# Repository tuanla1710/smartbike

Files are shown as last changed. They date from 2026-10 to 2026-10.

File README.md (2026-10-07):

# Smart Bike Controller V1

Firmware điều khiển xe đạp điện trên ESP32-S3-WROOM-1-N8 (flash 8 MB). Bản thiết kế nằm ở [docs/design/README.md](docs/design/README.md).

Build ảnh firmware chạy trên máy Linux và không cần mạch. Mạch chỉ cần khi nạp và mở console USB.

## Yêu cầu

| Thành phần | Ghi chú |
| --- | --- |
| Linux | Host đã dùng để cài ESP-IDF |
| Python 3 | Lệnh là `python3` |
| GCC | Dùng cho bộ đối chiếu luật điều khiển trên host |
| ESP-IDF v5.5.5 | Nằm ở `sources/esp-idf` |
| CMake và Ninja | ESP-IDF trên Linux không tự tải hai công cụ này |

## Cài ESP-IDF lần đầu

Từ thư mục gốc của repo:

```bash
git clone --depth 1 --branch v5.5.5 --recurse-submodules --shallow-submodules \
  https://github.com/espressif/esp-idf.git sources/esp-idf
cd sources/esp-idf
./install.sh esp32s3
python3 tools/idf_tools.py install cmake ninja
cd ../..
```

`install.sh` tải toolchain Xtensa và Python vào `~/.espressif`. Lệnh `idf_tools.py` tải CMake và Ninja vào cùng chỗ khi máy chưa có hai gói đó.

Mỗi terminal mới phải nạp môi trường trước khi gọi `idf.py`:

```bash
. sources/esp-idf/export.sh
```

Dấu chấm đầu dòng là bắt buộc. Sau khi nạp, `idf.py --version` in `ESP-IDF v5.5.5`.

## Kiểm tra luật điều khiển trên host

Bước này biên dịch lõi C bằng GCC của máy và so với giả lập Python. Chạy trước khi nạp mạch:

```bash
make -C firmware/host
cd firmware
python3 host/diff_oracle.py
python3 -m unittest sim.test_sim
```

Kết quả đúng là `ok files=8 cases=14` và unittest OK. REPL giả lập:

```bash
cd firmware
python3 -m sim
```

## Build firmware

```bash
. sources/esp-idf/export.sh
cd firmware
idf.py set-target esp32s3
idf.py build
```

`set-target` chỉ cần lần đầu, khi chưa có `firmware/sdkconfig`. Các lần sau chỉ cần `idf.py build`.

Ảnh nạp: `firmware/build/smartbike.bin`. Phân vùng ứng dụng là 2 MB (`firmware/partitions_8mb.csv`).

## Nạp và mở console

Cắm cáp USB vào cổng USB của module. Cổng thường là `/dev/ttyACM0`. Kiểm tra bằng `ls /dev/ttyACM*`.

Trong thư mục `firmware/`, shell đã nạp `export.sh`:

```bash
idf.py -p /dev/ttyACM0 flash monitor
```

Dòng đầu console là `ok boot`. Thoát màn hình log bằng Ctrl+].

Nạp lại mà không mở log:

```bash
idf.py -p /dev/ttyACM0 flash
```

Console đi qua USB Serial/JTAG. Lệnh debug nằm ở [docs/design/09-debug-commands.md](docs/design/09-debug-commands.md).

Chạy kịch bản portable trên mạch đã nạp (cần `pyserial`):

```bash
python3 -m pip install -r tools/requirements.txt
python3 -m sim.runner --port /dev/ttyACM0 scenarios/portable/boot.txt
```

Lệnh `hw` và `tick` chỉ có trên giả lập. Trên mạch, `hw` trả `err sim-only`.

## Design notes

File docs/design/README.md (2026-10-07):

# Smart Bike Controller — PCB V1

Tài liệu này chốt bản thiết kế **PCB Smart Bike Controller V1** cho xe V5.

Sơ đồ nguyên lý KiCad đã có ERC sạch. Bản đặt linh kiện và hồ sơ chân nối cho khách nằm ở [đặc tả kết nối](../customer/SmartBike-V5-Ket-Noi.md). File thiết kế mở bằng `hardware/kicad/kicad.sh`.

Nếu một datasheet của linh kiện mua về khác bảng chân trong tài liệu này, datasheet thắng. Cập nhật lại tài liệu trước khi routing.

## Đọc theo thứ tự

| Tài liệu | Dùng khi |
| --- | --- |
| [01-architecture.md](01-architecture.md) | Nhìn toàn bộ hệ thống, phạm vi V1, các quyết định đã khóa |
| [02-schematic.md](02-schematic.md) | Vẽ từng sheet KiCad: net, chân, R/C, MOSFET, connector |
| [03-pcb-layout.md](03-pcb-layout.md) | Outline 70 × 50 mm, stackup 4 lớp, vùng đặt linh kiện, luật đồng |
| [04-firmware.md](04-firmware.md) | Map GPIO, địa chỉ I2C, state machine, hợp đồng với phần cứng |
| [05-bom-and-bringup.md](05-bom-and-bringup.md) | Designator, footprint, mục BOM, thứ tự cấp nguồn lần đầu |
| [Đặc tả kết nối](../customer/SmartBike-V5-Ket-Noi.md) | Bảng chân J1–J8, MOD1, I2C, UART, điểm đo — bản giao cho người tích hợp dây |
| [06-software.md](06-software.md) | Ngôn ngữ, cây source ESP-IDF, task, BLE, thứ tự viết |
| [07-software-architecture.md](07-software-architecture.md) | Tầng, mặt phẳng, luật phụ thuộc, hợp đồng dữ liệu giữa khối |
| [08-control-algorithms.md](08-control-algorithms.md) | Thuật toán điều khiển và flowchart Mermaid |
| [09-debug-commands.md](09-debug-commands.md) | Lệnh console USB để test và debug thủ công |
| [10-implementation-checklist.md](10-implementation-checklist.md) | Thứ tự viết firmware và điều kiện pass từng bước |
| [11-automation-test.md](11-automation-test.md) | Test tự động và bộ giả lập phần cứng |

## Thông số đã khóa

| Hạng mục | Giá trị |
| --- | --- |
| Tên | Smart Bike Controller V1 |
| Kích thước | 70.00 × 50.00 mm |
| Số lớp | 4 |
| Độ dày | 1.6 mm |
| Nguồn vào PCB | 5 V duy nhất |
| MCU | ESP32-S3-WROOM-1-N8 |
| Đèn, xi-nhan, còi | Low-side MOSFET, không relay |
| GPS | u-blox MAX-M10S + anten chip |
| LiDAR trước | Module VL53L1X, tầm khoảng 4 m |
| IMU | BMI270 |
| Ánh sáng | BH1750 |
| Đo V / I / P / năng lượng | INA228 + shunt 10 mΩ |
| Lập trình | USB-C, USB Serial/JTAG của ESP32-S3 |
| Radio | Wi-Fi và Bluetooth trên module |
| Firmware về sau | OTA trên flash 8 MB |

48 V không vào PCB. V1 không có 5G, CAN, camera, stage nguồn 48 V, hay MCU phụ.

## Việc còn mở trước khi đặt hàng PCB

1. Đo dòng còi V5, rồi chọn một trong hai footprint còi (`Q8A` hoặc `Q8B`).
2. Đo dòng từng đèn. `Si2302CDS` chỉ được gắn cho kênh dưới 1 A liên tục.
3. Chọn MPN anten GPS và chép mạng phối hợp từ datasheet anten vào `R17`, `C20`, `C21`.
4. Đối chiếu thứ tự chân module VL53L1X mua về với header `MOD1` trước khi khóa footprint.

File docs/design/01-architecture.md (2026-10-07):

# 1. Kiến trúc V1

## 1.1 Mục tiêu

PCB này là bộ điều khiển xe đạp điện V5. Nó lấy duy nhất 5 V từ nguồn ngoài, đo điện áp / dòng / công suất, nuôi ESP32-S3 ở 3.3 V, và đóng các tải 5 V bằng MOSFET kéo xuống mass.

Tải V1:

- đèn pha
- đèn hậu
- đèn phanh
- xi-nhan trái, xi-nhan phải, hazard
- còi
- một kênh AUX

Cảm biến V1:

- GPS để biết vị trí
- LiDAR phía trước, khoảng 4 m, để cảnh báo vật cản
- IMU để chống trộm, phát hiện chuyển động, ngã, va chạm, và đánh thức MCU
- cảm biến ánh sáng để bật đèn pha tự động

Người lái nói chuyện với xe qua công tắc tay lái và Bluetooth. USB-C dùng để nạp firmware và, khi chưa cắm nguồn xe, nuôi mạch ở mức dòng USB mặc định.

## 1.2 Phạm vi không làm trên PCB này

- Không đưa 48 V, pin xe, hay stage công suất động cơ vào PCB.
- Không dùng relay.
- Không thêm Arduino, STM32, hay MCU thứ hai.
- Không thêm 5G, CAN, camera, màn hình, hay sạc pin.
- Không tắt buck bằng GPIO. Ngủ của V1 là deep sleep của ESP32.

## 1.3 Sơ đồ khối nguồn

```
J1 +5V_IN
    │
    F1 3A
    │
    Q1  DMG2305UX          chống đảo cực
    │
    D2  SMAJ5.0A           TVS xuống GND
    │
    +5V_PROT
    │
    D3  SS54               chặn dòng chảy ngược ra J1
    │
    └──────────┬─────────── D4 SS34 ← F2 ← USB VBUS
               │
           +5V_MERGED
               │
           R2 10 mΩ        INA228 đo qua shunt
               │
           +5V_SYS
               │
     ┌─────────┼─────────┬──────────────┐
     │         │         │              │
   đèn       còi       AUX         U2 TPS62162-Q1
 (low-side) (low-side) (low-side)       │
                                         +3V3
                                         │
                              ESP32, cảm biến, GPS, USB I/O
```

Nhánh `5V LIGHTS`, `5V HORN`, `5V AUX` trong sơ đồ khối ban đầu là các MOSFET low-side từng kênh. Không thêm MOSFET high-side theo nhóm.

## 1.4 Sơ đồ khối tín hiệu

```
                         ESP32-S3-WROOM-1
                                │
           ┌────────────────────┼────────────────────┐
           │                    │                    │
         I2C                  UART                 GPIO
           │                    │                    │
     GPIO8 SDA            GPIO17 ← GPS TXD      đèn / còi / AUX
     GPIO9 SCL            GPIO18 → GPS RXD      công tắc tay lái
           │                                      IMU INT, LiDAR
     INA228  0x40
     BMI270  0x68
     BH1750  0x23
     VL53L1X 0x29
```

## 1.5 Quyết định đã khóa

| ID | Quyết định |
| --- | --- |
| QĐ1 | USB VBUS và nguồn J1 gặp nhau sau hai diode Schottky. `Q1` có source phía cầu chì và drain phía `+5V_PROT`. Khi USB kéo `+5V_PROT` lên, diode thân dẫn ngược về J1 và kênh cũng mở vì gate vẫn ở mass. `D3` nằm sau `Q1` để chặn đường đó. |
| QĐ2 | Shunt của INA228 nằm sau điểm cộng nguồn, trên đường vào `+5V_SYS`. Số đo là dòng thực sự nuôi đèn, còi, AUX và buck. |
| QĐ3 | `HAZARD_SW` không có GPIO riêng. Hai diode kéo `LEFT_SW` và `RIGHT_SW` xuống thấp khi bấm hazard. Firmware hiểu hazard khi cả hai chân cùng thấp. |
| QĐ4 | Sáu kênh đèn và AUX dùng `Si2302CDS`. Kênh còi có hai footprint loại trừ nhau. Chỉ hàn một cái sau khi đo dòng còi. |
| QĐ5 | Mỗi kênh tải có diode hồi tiếp. Còi là tải cảm, và dây đèn trên xe đủ dài để tạo xung áp. |
| QĐ6 | LiDAR là module VL53L1X hàn qua header, không phải die trần. |
| QĐ7 | Module MCU là `ESP32-S3-WROOM-1-N8`: flash 8 MB, không PSRAM octal. Đủ chỗ cho OTA hai phân vùng. GPIO35–37 không bị PSRAM chiếm, và V1 cũng không dùng chúng. |
| QĐ8 | Buck luôn bật khi có `+5V_SYS`. `EN` nối thẳng rail 5 V. |
| QĐ9 | I2C V1 chạy 100 kHz. |
| QĐ10 | `V_BCKP` của GPS nối 3.3 V. V1 không có pin backup; mất nguồn là mất hot start. |

## 1.6 Ngân sách dòng

Cầu chì `F1` là trần cứng: **3 A** trên đường nguồn xe.

| Nhánh | Trần dùng khi thiết kế |
| --- | --- |
| Toàn bộ `+5V_SYS` | 2.5 A liên tục, để cầu chì 3 A còn dư |
| Mỗi kênh `Si2302CDS` | 1 A liên tục |
| Còi | Chưa biết. Nếu một mình còi đã trên 3 A thì V1 không kéo được; phải đổi cầu chì, shunt, connector và MOSFET |
| USB | CC 5.1 kΩ khai báo thiết bị USB mặc định. Firmware và cảm biến chạy được trên USB. Đèn và còi không được bật khi chỉ có USB |
| `+3V3` | TPS62162-Q1 cấp tối đa 1 A. Đỉnh Wi-Fi của ESP32-S3 nằm trong trần này nếu GPS và LiDAR đang ở dòng bình thường |

Ước lượng 3.3 V khi đang chạy: ESP32 khoảng vài trăm mA lúc phát Wi-Fi, GPS khoảng 30 mA, module VL53L1X vài chục mA, BMI270 / BH1750 / INA228 dưới 2 mA cộng lại.

## 1.7 Ngủ và đánh thức

`U2` không bị cắt điện. Dòng tĩnh của buck khoảng 17 µA, cộng thêm cảm biến nếu firmware không đưa chúng vào standby.

| Mode | Phần cứng |
| --- | --- |
| SLEEP | ESP32 deep sleep. VL53L1X bị kéo `XSHUT` thấp. GPS để firmware đưa vào backup software nếu cần. BMI270 giữ một ngắt chuyển động |
| PARKING / ALARM / RIDING | ESP32 chạy. Chi tiết trạng thái nằm ở tài liệu firmware |

Nguồn đánh thức V1 là `GPIO38` (`IMU_INT`). Không có chân nguồn riêng để bật buck.

## 1.8 Bản đồ GPIO đã chốt

| GPIO | Net | Hướng | Chức năng |
| --- | --- | --- | --- |
| GPIO4 | `LIDAR_XSHUT` | ra | Reset / shutdown VL53L1X, active-low ở phía sensor |
| GPIO5 | `LIDAR_INT` | vào | Ngắt VL53L1X, open-drain, có pull-up |
| GPIO6 | `HORN_GATE` | ra | Cổng MOSFET còi |
| GPIO7 | `HEADLIGHT_GATE` | ra | Cổng MOSFET đèn pha |
| GPIO8 | `I2C_SDA` | hai chiều | I2C data |
| GPIO9 | `I2C_SCL` | ra | I2C clock |
| GPIO10 | `LEFT_GATE` | ra | Xi-nhan trái |
| GPIO11 | `RIGHT_GATE` | ra | Xi-nhan phải |
| GPIO12 | `TAIL_GATE` | ra | Đèn hậu |
| GPIO13 | `BRAKE_GATE` | ra | Đèn phanh |
| GPIO15 | `LEFT_SW` | vào | Công tắc trái, active-low |
| GPIO16 | `RIGHT_SW` | vào | Công tắc phải, active-low |
| GPIO17 | `GPS_TXD` | vào | UART RX của ESP32, nối TXD của MAX-M10S |
| GPIO18 | `GPS_RXD` | ra | UART TX của ESP32, nối RXD của MAX-M10S |
| GPIO19 | `USB_D_N` | USB | D− |
| GPIO20 | `USB_D_P` | USB | D+ |
| GPIO21 | `HORN_SW` | vào | Công tắc còi, active-low |
| GPIO38 | `IMU_INT` | vào | BMI270 INT1, đánh thức |
| GPIO39 | `LIGHT_SW` | vào | Công tắc đèn, active-low |
| GPIO40 | `BRAKE_SW` | vào | Công tắc phanh, active-low |
| GPIO41 | `AUX_GATE` | ra | Cổng MOSFET AUX |
| GPIO42 | `STATUS_LED` | ra | LED trạng thái trên PCB, active-high |

`GPIO0` chỉ phục vụ nút BOOT trên PCB, pull-up 10 kΩ. Không phải chức năng xe.

Các chân không dùng, để hở: `GPIO1`, `GPIO2`, `GPIO3`, `GPIO14`, `GPIO35`, `GPIO36`, `GPIO37`, `GPIO43`, `GPIO44`, `GPIO45`, `GPIO46`, `GPIO47`, `GPIO48`.

`GPIO0`, `GPIO3`, `GPIO45`, `GPIO46` là chân strapping. `GPIO45` và `GPIO46` có pull-down yếu bên trong và phải được thả nổi. `GPIO3` thả nổi. Không kéo `GPIO45` lên cao.

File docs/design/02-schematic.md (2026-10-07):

# 2. Schematic V1 — hợp đồng cho KiCad

Mỗi mục dưới đây là một sheet. Tên net viết hoa, dùng đúng chuỗi này trên mọi sheet. KiCad cần `PWR_FLAG` trên `+5V_IN` và `GND`.

Quy tắc chung:

- Tụ gốm, điện áp ghi là điện áp định mức, không phải điện áp làm việc.
- Điện trở 1% 0603 trừ khi ghi khác.
- Cổng MOSFET đèn có series 100 Ω và pull-down 100 kΩ xuống `GND`. Pull-down giữ tải tắt trong lúc ESP32 còn đang reset.
- Firmware phải ghi mức thấp ra mọi chân gate trước khi đổi chân đó sang output.

## 2.1 Sheet `power`

### Chuỗi nguồn xe

```
J1-1 +5V_IN
  │
 F1 3A
  │
 +5V_FUSED ──── Q1 source (DMG2305UX)
                 Q1 drain  ──── +5V_PROT
                 Q1 gate   ── R1 100k ── GND
                 D1 BZT52C5V6: cathode = source, anode = gate

D2 SMAJ5.0A: cathode = +5V_PROT, anode = GND

+5V_PROT ── D3 SS54 anode→cathode ── +5V_MERGED
```

`Q1` là P-MOSFET high-side. **Source ở `+5V_FUSED`, drain ở `+5V_PROT`.** Đảo hai chân này thì cắm đúng cực cũng không nuôi được mạch. Chân SOT-23 của DMG2305UX: 1 = Gate, 2 = Source, 3 = Drain. Đối chiếu lại footprint KiCad với datasheet Diodes trước khi xuất gerber.

Zener `D1` kẹp `VGS` khoảng −5.6 V. Điện áp làm việc chỉ khoảng −5 V; zener là lớp chặn khi có xung.

`D2` đặt sau MOSFET chống đảo cực. Chiều TVS một chiều: cathode lên rail, anode xuống mass. SMAJ5.0A có điện áp standoff 5.0 V, đánh thủng khoảng 6.4 V, kẹp khoảng 9.2 V ở dòng xung danh định. TPS62162-Q1 chịu được tới 17 V. Tải đèn trong xung đó có thể thấy quá 5 V cho tới khi `F1` đứt; đây là đặc điểm của TVS này, chấp nhận cho V1.

### Cộng nguồn với USB, không back-feed

```
+5V_PROT ── D3 SS54 ──┐
                      ├── +5V_MERGED
USB_VBUS ── F2 ── D4 SS34 ──┘
```

`D3` và `D4` là diode Schottky, anode phía nguồn, cathode phía `+5V_MERGED`.

Khi chỉ cắm USB, `+5V_SYS` thấp hơn VBUS khoảng điện áp rơi của `D4` (khoảng 0.3–0.4 V). Khi chỉ có nguồn xe, sụt nằm trên `D3`. Hai nguồn không được cấp ngược cho nhau.

`F2` là PTC 1.1 A hold trên đường USB. Đường USB không được phép nuôi còi hay cả cụm đèn.

### Đo công suất

```
+5V_MERGED ── R2 10 mΩ 2512 ── +5V_SYS

U1 INA228
  IN+  = +5V_MERGED     (phía nguồn của shunt)
  IN−  = +5V_SYS        (phía tải của shunt)
  VBUS = +5V_SYS
  VS   = +3V3
  GND  = GND
  A1   = GND
  A0   = GND
  SCL  = I2C_SCL
  SDA  = I2C_SDA
  ALERT = ALERT, R3 10k lên +3V3
```

Địa chỉ I2C: **0x40**.

Đi dây sense: hai đường `IN+` và `IN−` tách từ mép trong của hai pad shunt, không đi chung với đồng dòng mạnh. Đây là kết nối Kelvin.

`C1` 100 nF từ `VS` xuống `GND`, sát U1.

`C2` 22 µF 10 V X5R từ `+5V_SYS` xuống `GND`, đặt gần cụm MOSFET.

Ở 3 A, sụt shunt là 30 mV, tán nhiệt khoảng 90 mW. Điện trở shunt: **10 mΩ, 1%, 1 W, 2512**. Dải ADC V1 dùng thang ±163.84 mV (`ADCRANGE = 0`) để dòng xung của còi không bị cắt ngọn. Hằng số hiệu chuẩn nằm ở tài liệu firmware.

`ALERT` không vào GPIO ở V1. Firmware đọc INA228 theo chu kỳ. Chân `ALERT` vẫn có pull-up để không bị nổi.

### Buck 5 V → 3.3 V

`U2` = **TPS62162-Q1**, gói WSON-8 DSG 2 × 2 mm, đầu ra cố định 3.3 V, 1 A. Mã đặt hàng gợi ý: `TPS62162QDSGTQ1`.

| Chân | Tên | Nối |
| --- | --- | --- |
| 1 | PGND | GND, và exposed pad |
| 2 | VIN | `+5V_SYS` |
| 3 | EN | `+5V_SYS` |
| 4 | AGND | GND |
| 5 | FB | AGND (nối mass). Bản 3.3 V cố định; datasheet khuyên nối FB xuống AGND |
| 6 | VOS | `+3V3` |
| 7 | SW | `L1` phía buck |
| 8 | PG | `PGOOD`, kéo lên `+3V3` bằng `R4` 100 kΩ. Không vào MCU |
| EP | thermal | GND, vài via xuống lớp GND |

Phụ kiện, đúng bộ LC khuyến nghị của TI:

| Ref | Giá trị | Việc |
| --- | --- | --- |
| C3 | 10 µF, 25 V, X5R, 0805 | VIN xuống GND, sát chân 2 |
| C4 | 100 nF, 25 V, 0402 | VIN xuống GND, sát hơn C3 |
| L1 | 2.2 µH, Isat ≥ 1.6 A, có vỏ chắn | SW tới `+3V3`. Gợi ý: TDK VLF3012ST-2R2M1R4 hoặc tương đương shielded 3 × 2.8 mm |
| C5 | 22 µF, 10 V, X5R, 0805 | `+3V3` xuống GND, ngay sau cuộn |
| R4 | 100 kΩ | `PGOOD` lên `+3V3` |

Vòng dòng đầu vào: `C3` → VIN → PGND → GND của `C3` phải ngắn. Node `SW` giữ diện tích nhỏ, không kéo xuống dưới anten GPS.

## 2.2 Sheet `usb`

`J8` là USB-C 16 chân, receptacle bảng, ví dụ kiểu `TYPE-C-31-M-12`. Chỉ dùng USB 2.0. Các chân SuperSpeed để hở.

| Chân receptacle | Net |
| --- | --- |
| A4, A9, B4, B9 | `USB_VBUS` |
| A5 | `CC1` |
| B5 | `CC2` |
| A6, B6 | `USB_D_P` |
| A7, B7 | `USB_D_N` |
| A1, A12, B1, B12, shield | `GND` |
| A8, B8 (SBU) | để hở |
| TX/RX SuperSpeed | để hở |

| Ref | Giá trị | Việc |
| --- | --- | --- |
| R5 | 5.1 kΩ | `CC1` xuống `GND` |
| R6 | 5.1 kΩ | `CC2` xuống `GND` |
| U3 | USBLC6-2SC6 | ESD. `VBUS` pin của USBLC6 vào `USB_VBUS`, I/O vào D+ và D− phía connector, GND xuống mass |
| C6 | 100 nF | `USB_VBUS` xuống `GND`, sát J8 |
| R7 | 22 Ω | series trên `USB_D_P`, sát module ESP32 |
| R8 | 22 Ω | series trên `USB_D_N`, sát module ESP32 |
| C7 | DNP, 0402 | từ phía ESP32 của D+ xuống GND, vị trí để sẵn theo hướng dẫn Espressif |
| C8 | DNP, 0402 | tương tự cho D− |

`R7`/`R8` nằm gần module, không nằm gần connector. Cặp D+/D− là differential 90 Ω.

`F2` và `D4` chỉ đặt một lần, trên sheet `power`. Sheet `usb` giao ra net `USB_VBUS`.

ESP32-S3 không đàm phán USB-PD. Hai điện trở 5.1 kΩ chỉ xin dòng USB mặc định (tối đa khoảng 500 mA ở host tuân thủ). Đủ để nạp firmware và chạy MCU cùng cảm biến.

## 2.3 Sheet `mcu`

`U4` = **ESP32-S3-WROOM-1-N8**. Anten PCB in trên module. Không dùng bản WROOM-1U.

Chân nguồn và điều khiển:

| Chân module | Tên | Nối |
| --- | --- | --- |
| 1 | GND | `GND` |
| 2 | 3V3 | `+3V3` |
| 3 | EN | `EN` |
| 40 | GND | `GND` |
| 41 | EPAD | `GND` |

| Ref | Giá trị | Việc |
| --- | --- | --- |
| C9 | 10 µF, 10 V, 0603 | `+3V3` xuống GND, sát chân 2 |
| C10 | 100 nF, 10 V, 0402 | `+3V3` xuống GND, sát chân 2 |
| R9 | 10 kΩ | `EN` lên `+3V3`. Chân EN không được để nổi |
| C11 | 1 µF | `EN` xuống `GND`, tạo trễ bật |
| SW1 | nút nhấn 6 × 6 mm | `EN` xuống `GND`, reset |
| R10 | 10 kΩ | `GPIO0` lên `+3V3` |
| SW2 | nút nhấn 6 × 6 mm | `GPIO0` xuống `GND`, BOOT |

LED trạng thái, active-high:

```
GPIO42 ── R11 330 Ω ── D5 anode
D5 cathode ── GND
```

`D5` là LED xanh 0603. Dòng khoảng 4 mA.

`GPIO19` nối net `USB_D_N` sau `R8`. `GPIO20` nối net `USB_D_P` sau `R7`.

Các GPIO chức năng nối đúng bảng ở [01-architecture.md](01-architecture.md). Không nối gì vào GPIO45 và GPIO46.

UART GPS không dùng chân mặc định của UART1 trên module (`IO17` mặc định là `U1TXD`, `IO18` mặc định là `U1RXD`). Firmware phải gán qua GPIO matrix: RX = GPIO17, TX = GPIO18.

## 2.4 Sheet `sensors`

Một cặp pull-up cho cả bus. Nếu module VL53L1X đã có pull-up riêng, gỡ pull-up trên module hoặc không lắp `R13`/`R14`, chỉ để lại một cặp.

| Ref | Giá trị | Việc |
| --- | --- | --- |
| R13 | 4.7 kΩ | `I2C_SDA` lên `+3V3` |
| R14 | 4.7 kΩ | `I2C_SCL` lên `+3V3` |

### U1 INA228

Đã nối ở sheet power. Trên sheet này chỉ là các net `I2C_SDA`, `I2C_SCL`, `ALERT`.

### U5 BMI270

Gói LGA-14, 2.5 × 3.0 mm. I2C vì `CSB` nối `+3V3`.

| Chân | Tên | Nối |
| --- | --- | --- |
| 1 | SDO | `GND` → địa chỉ **0x68** |
| 2 | ASDX | để hở |
| 3 | ASCX | để hở |
| 4 | INT1 | `IMU_INT` = GPIO38 |
| 5 | VDDIO | `+3V3` |
| 6 | GNDIO | `GND` |
| 7 | GND | `GND` |
| 8 | VDD | `+3V3` |
| 9 | INT2 | để hở |
| 10 | OCSB | để hở |
| 11 | OSDO | để hở |
| 12 | CSB | `+3V3` |
| 13 | SCx | `I2C_SCL` |
| 14 | SDx | `I2C_SDA` |

| Ref | Giá trị | Việc |
| --- | --- | --- |
| C13 | 100 nF | VDD xuống GND, trong vòng 1 mm |
| C14 | 100 nF | VDDIO xuống GND, trong vòng 1 mm |

Đặt BMI270 xa vùng đồng chịu lực cơ khí lớn (góc lỗ vít, mép kẹp vỏ) để giảm lệch offset do strain.

Firmware phải nạp file init của Bosch trước khi đọc gia tốc và con quay.

### U6 BH1750FVI

Gói WSOF6. ADDR xuống mass → địa chỉ **0x23**.

| Chân | Tên | Nối |
| --- | --- | --- |
| 1 | VCC | `+3V3` |
| 2 | ADDR | `GND` |
| 3 | GND | `GND` |
| 4 | SDA | `I2C_SDA` |
| 5 | DVI | nút RC bên dưới |
| 6 | SCL | `I2C_SCL` |

`DVI` là chân reset bất đồng bộ và là điện áp tham chiếu I2C. Nó phải ở thấp sau khi VCC đã lên, rồi mới lên cao.

```
+3V3 ── R12 10k ── DVI ── C16 100 nF ── GND
C15 100 nF từ VCC xuống GND
```

Hằng số RC khoảng 1 ms, dài hơn thời gian VCC tăng, nên thỏa điều kiện tối thiểu 1 µs của datasheet ROHM.

Cửa sổ quang của BH1750 phải nhìn ra ngoài vỏ, không bị che bởi pin header hay thành nhôm.

### MOD1 VL53L1X

Module, không vẽ mạch sensor trần. Header 1 × 6, pitch 2.54 mm, net theo thứ tự sau. Silk phải in tên chân. Trước khi khóa footprint, đối chiếu đúng module sẽ mua: nhiều board GY-VL53L1X đảo SDA/SCL.

| Pin header | Net |
| --- | --- |
| 1 | `+3V3` |
| 2 | `GND` |
| 3 | `I2C_SDA` |
| 4 | `I2C_SCL` |
| 5 | `LIDAR_XSHUT` |
| 6 | `LIDAR_INT` |

| Ref | Giá trị | Việc |
| --- | --- | --- |
| R15 | 10 kΩ | `LIDAR_XSHUT` lên `+3V3` |
| R16 | 10 kΩ | `LIDAR_INT` lên `+3V3` |
| C17 | 100 nF | `+3V3` xuống GND tại header |

Địa chỉ mặc định **0x29**. `XSHUT` mức cao thì sensor chạy; GPIO4 kéo thấp để shutdown. Ngắt là open-drain.

Module đặt sát mép trước, cửa sổ laser nhìn về phía trước xe, không bị đồng hay vỏ che.

## 2.5 Sheet `gps`

`U7` = **u-blox MAX-M10S**. Đối chiếu pinout với datasheet UBX-20035208 của đúng lô mua. Các bản khác nhau gọi chân 15 là `Reserved` hoặc `VIO_SEL`. Cả hai trường hợp V1 đều **để hở chân 15**. Không nối chân 15 xuống mass: nếu đó là `VIO_SEL`, mass sẽ chọn IO 1.8 V trong khi bus UART của ESP32 là 3.3 V.

| Chân | Tên | Nối |
| --- | --- | --- |
| 1, 10, 12 | GND | `GND` |
| 2 | TXD | `GPS_TXD` → GPIO17 |
| 3 | RXD | `GPS_RXD` ← GPIO18 |
| 4 | TIMEPULSE | để hở |
| 5 | EXTINT | để hở |
| 6 | V_BCKP | `+3V3` |
| 7 | V_IO | `+3V3` |
| 8 | VCC | `+3V3` |
| 9 | RESET_N | để hở |
| 11 | RF_IN | net `GPS_RF` |
| 13 | LNA_EN | để hở. Không dùng chân này làm GPIO |
| 14 | VCC_RF | để hở khi dùng anten thụ động |
| 15 | Reserved / VIO_SEL | để hở |
| 16 | SDA | để hở. Không nối vào bus I2C của xe |
| 17 | SCL | để hở |
| 18 | SAFEBOOT_N | để hở |

| Ref | Giá trị | Việc |
| --- | --- | --- |
| C18 | 1 µF | VCC xuống GND |
| C19 | 100 nF | VCC xuống GND, sát chân 8 |

UART mặc định của module: 9600 8N1. Firmware được phép nâng baud sau khi đã bắt tay.

### Anten

`AE1` là anten chip GPS L1 1575.42 MHz, đặt ở mép trái PCB. Mạng pi:

```
U7 RF_IN ── R17 ── AE1 feed
             │
            C20 xuống GND (DNP cho tới khi có giá trị datasheet)
AE1 feed ── C21 xuống GND (DNP cho tới khi có giá trị datasheet)
```

`R17` khởi tạo là 0 Ω chỉ để mạch thông. Trước khi xuất gerber, thay `R17`, `C20`, `C21` bằng mạng phối hợp in trong datasheet của đúng MPN anten đã chọn. Đường `GPS_RF` là CPWG 50 Ω trên L1, lớp tham chiếu L2, không via.

MAX-M10S đã có SAW và LNA trong module. Anten thụ động không cần thêm LNA. `VCC_RF` và `LNA_EN` để hở.

## 2.6 Sheet `outputs`

Mọi kênh là low-side:

```
+5V_SYS ── tải ── net *_N ── drain MOSFET
                              source ── GND
GPIO ── 100 Ω ── gate
                 │
               100 kΩ
                 │
                GND

Diode hồi tiếp: cathode = +5V_SYS, anode = net *_N
```

| Kênh | MOSFET | Gate | Net drain | Series | Pull-down | Flyback | Connector |
| --- | --- | --- | --- | --- | --- | --- | --- |
| Đèn pha | Q2 Si2302CDS | `HEADLIGHT_GATE` GPIO7 | `HEADLIGHT_N` | R18 100 | R25 100k | D6 SS14 | J3-2 |
| Đèn hậu | Q3 Si2302CDS | `TAIL_GATE` GPIO12 | `TAIL_N` | R19 100 | R26 100k | D7 SS14 | J4-2 |
| Đèn phanh | Q4 Si2302CDS | `BRAKE_GATE` GPIO13 | `BRAKE_N` | R20 100 | R27 100k | D8 SS14 | J4-3 |
| Trái | Q5 Si2302CDS | `LEFT_GATE` GPIO10 | `LEFT_N` | R21 100 | R28 100k | D9 SS14 | J5-2 |
| Phải | Q6 Si2302CDS | `RIGHT_GATE` GPIO11 | `RIGHT_N` | R22 100 | R29 100k | D10 SS14 | J5-3 |
| AUX | Q7 Si2302CDS | `AUX_GATE` GPIO41 | `AUX_N` | R23 100 | R30 100k | D11 SS14 | J7-2 |
| Còi | Q8A hoặc Q8B | `HORN_GATE` GPIO6 | `HORN_N` | R24 100 | R31 100k | D12 SS34 | J6-2 |

Chân SOT-23 của Si2302CDS: đối chiếu datasheet Vishay khi gán footprint. Thông thường 1 = Gate, 2 = Source, 3 = Drain. Không lấy nhầm footprint P-channel.

`Q8A` là Si2302CDS, SOT-23. `Q8B` là MOSFET logic-level TO-252, MPN để trống. Gate, drain, source của `Q8A` và `Q8B` song song. **Chỉ hàn một trong hai.** Cả hai để DNP trên BOM cho tới khi có số đo dòng còi.

| Dòng còi đo được | Lắp |
| --- | --- |
| Dưới 1 A | Q8A Si2302CDS |
| 1 A đến 3 A | Q8B, MOSFET logic-level, RDS(on) thấp, VGS(th) đủ mở ở 3.3 V. Ứng viên để đánh giá: IRLR8726 hoặc tương đương TO-252. Chốt MPN trong BOM trước khi lắp |
| Trên 3 A | Dừng. Cầu chì, shunt, J1 và J6 của V1 không chịu được. Không vá bằng một MOSFET lớn hơn trên cùng PCB này |

`D12` là SS34 vì năng lượng xung của còi lớn hơn đèn. Sáu diode đèn là SS14.

High-side của mọi tải là cùng net `+5V_SYS`, lấy từ chân 1 của từng connector tải.

## 2.7 Sheet `handlebar`

`J2` JST-XH 8 chân.

| Pin | Net | Trong PCB |
| --- | --- | --- |
| 1 | `+3V3` | nguồn pull-up cho cụm công tắc |
| 2 | `GND` | mass công tắc |
| 3 | `LEFT_SW` | GPIO15 |
| 4 | `RIGHT_SW` | GPIO16 |
| 5 | `HORN_SW` | GPIO21 |
| 6 | `LIGHT_SW` | GPIO39 |
| 7 | `HAZARD_SW` | không vào GPIO |
| 8 | `BRAKE_SW` | GPIO40 |

Mỗi công tắc trên tay lái nối giữa chân tín hiệu và `GND`. Mức tác động là thấp.

Với từng net `LEFT_SW`, `RIGHT_SW`, `HORN_SW`, `LIGHT_SW`, `BRAKE_SW`, `HAZARD_SW`:

```
+3V3 ── 10 kΩ ── net ── 100 nF ── GND
                  │
                 J2
```

| Net | Pull-up | Tụ |
| --- | --- | --- |
| `LEFT_SW` | R32 10k | C22 100n |
| `RIGHT_SW` | R33 10k | C23 100n |
| `HORN_SW` | R34 10k | C24 100n |
| `LIGHT_SW` | R35 10k | C25 100n |
| `BRAKE_SW` | R36 10k | C26 100n |
| `HAZARD_SW` | R37 10k | C27 100n |

Tụ 100 nF lắp sẵn. Dây tay lái dài.

Hazard, không tốn GPIO:

```
LEFT_SW  ── D13 anode    D13 cathode ── HAZARD_SW
RIGHT_SW ── D14 anode    D14 cathode ── HAZARD_SW
```

`D13` và `D14` là BAT54. Khi `HAZARD_SW` bị công tắc kéo xuống mass, cả `LEFT_SW` và `RIGHT_SW` xuống khoảng 0.3 V. Khi chỉ bấm trái, diode ngược nên `RIGHT_SW` không bị kéo theo.

Firmware: hazard khi `LEFT_SW` và `RIGHT_SW` cùng thấp.

## 2.8 Connector tải

Tất cả là JST-XH, một loại crimp cho bản prototype. XH chịu khoảng 3 A. Nếu dòng còi đo được buộc phải đổi connector, J1 và J6 chuyển sang JST-VH ở bản sau; V1 vẫn vẽ XH.

| Ref | Pin | Net |
| --- | --- | --- |
| J1 | 1 | `+5V_IN` |
| J1 | 2 | `GND` |
| J3 | 1 | `+5V_SYS` |
| J3 | 2 | `HEADLIGHT_N` |
| J4 | 1 | `+5V_SYS` |
| J4 | 2 | `TAIL_N` |
| J4 | 3 | `BRAKE_N` |
| J5 | 1 | `+5V_SYS` |
| J5 | 2 | `LEFT_N` |
| J5 | 3 | `RIGHT_N` |
| J6 | 1 | `+5V_SYS` |
| J6 | 2 | `HORN_N` |
| J7 | 1 | `+5V_SYS` |
| J7 | 2 | `AUX_N` |

Silk mỗi connector ghi tên và số chân. Không dựa vào trí nhớ khi crimp.

## 2.9 Test point

Pad tròn 1.5 mm, xuyên lỗ hoặc SMD, có silk. Bắt buộc:

| TP | Net |
| --- | --- |
| TP1 | `+5V_IN` |
| TP2 | `+5V_SYS` |
| TP3 | `+3V3` |
| TP4 | `GND` |
| TP5 | `USB_D_P` |
| TP6 | `USB_D_N` |
| TP7 | `GPS_TXD` |
| TP8 | `GPS_RXD` |
| TP9 | `I2C_SDA` |
| TP10 | `I2C_SCL` |
| TP11 | `HEADLIGHT_GATE` |
| TP12 | `HORN_GATE` |
| TP13 | `LEFT_GATE` |
| TP14 | `RIGHT_GATE` |

Không đặt test point trên node `SW` của buck.

## 2.10 Thứ tự vẽ

1. `power` — gồm cả diode USB và shunt, vì các net nguồn sinh ra ở đây.
2. `usb` — J8, CC, ESD, series resistor.
3. `mcu` — module, EN, BOOT, LED.
4. `sensors` — I2C và ba thiết bị.
5. `gps` — UART và anten.
6. `outputs` — bảy kênh.
7. `handlebar` — J2 và hazard.

ERC phải sạch trước khi cập nhật PCB. Mọi chân để hở có chủ đích phải được đánh dấu no-connect, trừ các chân đã nói là để hở ở trên.

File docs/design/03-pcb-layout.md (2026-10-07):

# 3. PCB layout V1

Chỉ bắt đầu layout khi ERC của schematic đã sạch.

## 3.1 Tấm mạch

| Hạng mục | Giá trị |
| --- | --- |
| Outline | 70.00 × 50.00 mm |
| Gốc tọa độ | góc dưới-trái |
| Cạnh trước xe | y = 50 mm, mép trên |
| Cạnh sau, phía connector tải | y = 0 |
| Độ dày | 1.6 mm |
| Đồng | 1 oz cả bốn lớp |
| Via tín hiệu | khoan 0.3 mm, pad 0.6 mm |
| Via GND dưới exposed pad | khoan 0.25–0.30 mm, vài via trong pad U2 và U4 |
| Lỗ bắt vít | 4 × M2 (khoan 2.2 mm), tâm lỗ cách mép 3.5 mm, nếu lỗ trước không chạm vùng cấm anten thì giữ; nếu chạm thì bỏ hai lỗ trước |
| Fiducial | 3 fiducial 1.0 mm, cách mép ≥ 5 mm, không nằm trên vùng anten |

Silk mặt trên: `SMART BIKE V5  PCB V1` và `5V ONLY`.

## 3.2 Stackup

| Lớp | Vai trò |
| --- | --- |
| L1 | Linh kiện và tín hiệu |
| L2 | Mặt phẳng GND, liền nhất có thể |
| L3 | Power: polygon `+5V_SYS` và `+3V3` |
| L4 | Tín hiệu |

L2 không bị xẻ dưới đường USB, dưới module ESP32 (trừ vùng anten), hay dưới đường RF của GPS. L3 mang dòng tải; L1 bổ sung polygon ở kênh còi và ở đoạn shunt.

Không đổ `+5V_SYS` trên L2.

## 3.3 Vùng đặt

Nhìn từ phía trước xe, mặt top:

```
y = 50  FRONT
┌────────────────────────────────────────────┐
│ MOD1 VL53L1X          cửa sổ nhìn ra trước │
│                                            │
│ AE1 GPS          U5 BMI270        U4 ESP32 │
│ anten            U6 BH1750     anten module│
│ U7 MAX-M10S                      ở mép phải│
│                                            │
│ U2 buck          U1 INA228    Q2…Q8        │
│ F1 Q1 D2 D3              D6…D12            │
│ J1          J3  J4  J5  J6  J7             │
└────────────────────────────────────────────┘
y = 0   REAR
J2 có thể nằm cạnh trái nếu hàng XH phía sau không còn chỗ.
J8 USB-C nằm cạnh sau hoặc cạnh trái. Anten ESP32 chiếm mép phải, nên USB không đặt ở mép đó.
```

Hai vùng không trộn vào nhau:

- Phía trước và giữa: RF, ESP32, GPS, IMU, ánh sáng, LiDAR.
- Phía sau: cầu chì, buck, shunt, MOSFET, connector tải.

Khoảng cách tối thiểu giữa cuộn `L1` (node SW) và anten GPS: đặt buck ở góc sau, anten GPS ở mép trước-trái. Không đặt còi MOSFET cạnh module GPS.

## 3.4 ESP32

Module nằm mép phải, phần anten của module hướng ra ngoài cạnh phải.

Vùng cấm anten, theo hardware design guidelines của Espressif cho module có anten PCB:

- Không đồng trên **cả bốn lớp** dưới phần anten của module.
- Không linh kiện, không via, không đường mạch trong vùng đó.
- Anten module hướng ra mép mạch, phía ngoài không có đồng.
- USB và UART không đi sát anten.

`C9` và `C10` sát chân 2. Mass của hai tụ xuống L2 bằng via ngay cạnh pad GND.

## 3.5 GPS

- Anten chip ở mép trái, feed hướng vào trong.
- Cắt đồng theo đúng hình keep-out của datasheet anten đã chọn, trên các lớp mà datasheet yêu cầu. Thường là cắt L1 và không đổ đồng đối diện feed.
- Đường `GPS_RF` dài vừa đủ, CPWG 50 Ω, tham chiếu L2 liền, không via.
- `R17`, `C20`, `C21` sát chân `RF_IN`.
- Không cho node `SW`, cổng còi, hay đường `HORN_N` đi dưới module GPS.

## 3.6 Buck

Thứ tự vật lý sát nhau: `C3`/`C4` → `U2` → `L1` → `C5`.

- PGND và AGND gặp nhau tại exposed pad, rồi via xuống L2.
- Node `SW` chỉ là đoạn ngắn từ chân 7 tới `L1`.
- Không biến node `SW` thành test point.

## 3.7 Dòng mạnh

Shunt `R2` hướng sao cho đường dòng đi thẳng từ `+5V_MERGED` sang `+5V_SYS`. Hai đường sense rẽ từ mép pad, cặp với nhau, tới `IN+` và `IN−`.

| Đường | Đồng tối thiểu |
| --- | --- |
| `+5V_IN` tới `F1`, qua `Q1`, tới shunt | polygon, tương đương ≥ 3 mm trên 1 oz, hoặc rộng hơn trên L1 + L3 |
| `+5V_SYS` trục chính tới J3–J7 | polygon L3, và nhánh L1 ngắn tới từng connector |
| `HORN_N` từ J6 tới drain Q8 | polygon ≥ 4 mm, hoặc L1 + L3 nối via dày |
| Các net đèn `*_N` | ≥ 1.0 mm nếu dòng kênh dưới 1 A; tăng theo số đo thực |

MOSFET ngồi cạnh connector của chính nó. Không kéo `HORN_N` vòng lên vùng GPS.

`F1` gần J1. `D2` gần `Q1`, dây mass của TVS ngắn xuống via L2.

## 3.8 Tín hiệu

- I2C đi ngắn giữa ESP32, U1, U5, U6 và MOD1. Kéo xa khỏi node `SW` và khỏi polygon còi.
- Cặp USB 90 Ω ± 10%, cùng dài, cùng lớp, tham chiếu L2. Ít via. Nếu phải via, thêm via mass cạnh đó.
- `GPS_TXD` và `GPS_RXD` là đường chậm, vẫn không luồn dưới anten.
- Cổng MOSFET là tín hiệu số thường. Series 100 Ω đặt gần GPIO của ESP32.

## 3.9 LiDAR và ánh sáng

`MOD1` sát y = 50, thân module có thể nhô khỏi outline nếu datasheet module cần khoảng trống phía trước cửa sổ. Ghi vùng cấm cơ khí trên lớp User: không vít, không gân vỏ, không dây trong hình nón nhìn của VL53L1X.

BH1750 quay cửa sổ lên trên hoặc ra mép, nơi vỏ có lỗ ánh sáng. Không đặt ngay dưới header.

## 3.10 Trước khi xuất gerber

- ERC sạch, DRC sạch.
- Không đồng trong keep-out anten ESP32 và keep-out anten GPS.
- L2 còn liền dưới USB và dưới ESP32 phần không phải anten.
- Đã điền MPN anten và giá trị `R17`/`C20`/`C21`.
- Đã quyết định `Q8A` hoặc `Q8B`, footprint còn lại để DNP và không bị DRC hiểu nhầm là chưa nối. Hai MOSFET song song là cố ý.
- Silk đọc được tên J1–J8 và chiều chân 1.
- Không có net 48 V nào trong schematic.

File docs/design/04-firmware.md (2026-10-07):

# 4. Firmware V1 — hợp đồng với PCB

Firmware nằm ở `firmware/`. Phần này khóa những gì firmware phải giả định đúng với PCB V1. Ngôn ngữ, cây ESP-IDF, task và hợp đồng BLE nằm ở [06-software.md](06-software.md).

## 4.1 Cây module

Các khối dưới đây là ranh giới module, không phải cây file. Cây file thật nằm ở [06-software.md](06-software.md).

```
smartbike/
├── main/
├── power/
│   ├── power_monitor      INA228
│   └── power_modes        sleep / parking / riding
├── sensors/
│   ├── gps                MAX-M10S, UART
│   ├── lidar              VL53L1X
│   ├── imu                BMI270
│   └── light              BH1750
├── vehicle/
│   ├── lighting           pha, hậu, PWM
│   ├── turn_signal        trái, phải, hazard
│   ├── brake
│   └── horn
├── security/
│   ├── anti_theft
│   └── motion_detect
├── bluetooth/
├── usb/
└── config/
```

## 4.2 Chân và mức tích cực

Tất cả công tắc tay lái là **active-low**, có pull-up trên PCB. Firmware bật pull-up nội bộ là tùy chọn, không bắt buộc.

Tất cả gate MOSFET là **active-high**. Mức thấp nghĩa là tải tắt. Trong `app_main`, trước khi cấu hình thành output, ghi 0 cho GPIO6, GPIO7, GPIO10, GPIO11, GPIO12, GPIO13, GPIO41.

`STATUS_LED` (GPIO42) active-high.

`LIDAR_XSHUT` (GPIO4): mức cao cho sensor chạy, mức thấp để shutdown. Pull-up 10 kΩ trên PCB nên nếu GPIO thả nổi thì sensor bật. Lúc vào sleep, firmware phải chủ động kéo thấp.

`IMU_INT` (GPIO38) là nguồn đánh thức deep sleep.

UART GPS, bắt buộc gán qua GPIO matrix:

| Tín hiệu ESP32 | GPIO | Nối tới |
| --- | --- | --- |
| UART RX | GPIO17 | MAX-M10S TXD |
| UART TX | GPIO18 | MAX-M10S RXD |

Không dùng mapping mặc định UART1 của module, vì mapping đó đảo chiều so với bảng này.

USB để nguyên GPIO19 = D−, GPIO20 = D+.

## 4.3 Bus

| Bus | Cấu hình V1 |
| --- | --- |
| I2C | GPIO8 SDA, GPIO9 SCL, 100 kHz |
| UART GPS | 9600 8N1 lúc mở cổng. Baud cao hơn chỉ sau khi module đã trả lời |

| Thiết bị | Địa chỉ 7-bit |
| --- | --- |
| INA228 | 0x40 |
| BH1750 | 0x23 |
| VL53L1X | 0x29 |
| BMI270 | 0x68 |

Quét I2C lúc bring-up phải thấy đủ bốn địa chỉ khi `XSHUT` đang cao. GPS không xuất hiện trên bus này.

BMI270 cần nạp init blob của Bosch trước khi đọc số liệu.

## 4.4 INA228

| Tham số | Giá trị V1 |
| --- | --- |
| Rshunt | 0.010 Ω |
| Dòng lớn nhất dùng để tính `CURRENT_LSB` | 5.0 A |
| `CURRENT_LSB` | 5 / 2^19 = 9.536743164 µA |
| `SHUNT_CAL` | 1250 |
| `ADCRANGE` | 0, thang vi sai ±163.84 mV |

Công thức TI: `SHUNT_CAL = 13107.2e6 × CURRENT_LSB × Rshunt`. Với hai số trên, kết quả đúng bằng 1250.

`ALERT` không nối GPIO. Đọc voltage, current, power, energy bằng I2C. Energy dùng cho màn hình điện thoại qua BLE.

Nếu shunt thực tế không phải 10 mΩ 1%, đo lại và sửa `SHUNT_CAL`. Không hard-code bù trong nhiều file; để một hằng trong `config`.

## 4.5 Đèn

| Việc | Hành vi V1 |
| --- | --- |
| Đèn hậu | Bật khi trạng thái là RIDING |
| Đèn phanh | Bật khi `BRAKE_SW` thấp |
| Đèn pha tự động | Lux dưới 100 thì bật. Lux trên 200 thì tắt. Trong khoảng 100–200 giữ nguyên trạng thái |
| `LIGHT_SW` thấp | Ép đèn pha bật, bỏ qua lux |
| `LIGHT_SW` cao | Trở lại chế độ lux |
| Độ sáng | PWM LEDC 1 kHz, 10 bit, trên các chân đèn. Còi và phanh không PWM ở V1 |
| Xi-nhan | Nhấp nháy 1.25 Hz, duty 50%, khi đúng một trong hai công tắc trái/phải đang thấp |
| Hazard | Khi cả `LEFT_SW` và `RIGHT_SW` cùng thấp. Không đọc chân hazard riêng. Hai bên nháy cùng pha |

Hazard bằng phần cứng diode nên firmware chỉ cần quy tắc `HAZARD = LEFT + RIGHT`.

## 4.6 Còi

`HORN_SW` thấp thì `HORN_GATE` cao. Thả công tắc thì gate thấp ngay.

V1 không PWM còi. Nếu dòng còi chưa được ghi vào `config`, firmware không bật còi cùng lúc với toàn bộ đèn. Trần phần cứng là cầu chì 3 A. Giới hạn thời gian giữ còi, cắt khi mất số đo dòng hoặc quá dòng, và cách tính “đang bật” của xi-nhan nằm ở [08-control-algorithms.md](08-control-algorithms.md). Mức tích cực của gate không đổi.

## 4.7 State machine

```
SLEEP
  │  IMU_INT
  ▼
PARKING
  │  người dùng bắt đầu chạy (BLE hoặc điều kiện start trong config)
  ▼
RIDING
  │  dừng
  ▼
PARKING
  │  chuyển động đáng ngờ
  ▼
ALARM
```

| Trạng thái | Việc nhìn thấy được |
| --- | --- |
| SLEEP | Gate đều thấp. `LIDAR_XSHUT` thấp. ESP32 deep sleep, wake trên GPIO38 |
| PARKING | Đèn pha theo lux hoặc theo `LIGHT_SW`. IMU theo dõi. GPS có thể giữ fix chậm |
| RIDING | Đèn hậu bật. Phanh, xi-nhan, còi theo công tắc. LiDAR cảnh báo. GPS cập nhật |
| ALARM | Nháy đèn, bật còi theo chu kỳ, gửi vị trí GPS và sự kiện qua BLE |

Ngưỡng “chuyển động đáng ngờ”, thời gian còi báo động, và cách xác nhận start/stop để trong `config`, không rải trong từng module. Điều kiện biên của từng chuyển trạng thái, khoảng nghỉ giữa hai lần báo động, và hủy ngủ khi có chuyển động mới nằm ở [08-control-algorithms.md](08-control-algorithms.md).

LiDAR khoảng 4 m là cảnh báo, không phải phanh tự động. V1 không có actuator phanh.

BLE V1 mang: trạng thái xe, lux, khoảng cách LiDAR, cờ IMU, tọa độ GPS, và số đọc INA228 (V, I, P, energy). OTA là việc sau, flash 8 MB đã chừa chỗ; bootloader OTA không bắt buộc phải xong trong bản firmware đầu tiên lên mạch.

## 4.8 Thứ tự bật

1. Mọi gate ghi 0, cấu hình output.
2. I2C 100 kHz, quét bus.
3. INA228: ghi `SHUNT_CAL`, kiểm tra điện áp bus khoảng 5 V (hoặc khoảng 4.6 V nếu đang nuôi bằng USB).
4. BMI270 init, bật ngắt chuyển động trên INT1.
5. BH1750, VL53L1X (`XSHUT` cao), UART GPS.
6. Vào PARKING. Chỉ vào RIDING sau điều kiện start.

Nếu chỉ có USB, bước 6 vẫn chạy nhưng các gate đèn và còi giữ thấp.

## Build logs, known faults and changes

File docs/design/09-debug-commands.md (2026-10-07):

# 9. Lệnh test và debug thủ công

Console này là đường điều khiển bằng tay trên USB Serial/JTAG, cùng cổng nạp firmware. Mỗi lệnh kiểm tra một nhánh đã khóa ở [08-control-algorithms.md](08-control-algorithms.md). Lệnh không mở thêm hành vi xe. Lệnh chỉ đưa đầu vào mà nhịp 10 ms vốn đã có, hoặc in trạng thái nhịp đó đang giữ.

## 9.1 Đường đi của một dòng

Task `console` đọc stdin, phân tích một dòng, rồi trả lời. Task này không gọi GPIO, LEDC, I2C, hay deep sleep. Mức tải chỉ đổi khi nhịp `vehicle` xử lý lệnh hoặc đọc khối debug.

```mermaid
flowchart TD
  line["Một dòng USB"] --> parse{"Đúng cú pháp?"}
  parse -->|không| err["err syntax"]
  parse -->|có| kind{"Loại lệnh?"}
  kind -->|xem| snap["Đọc bản sao snapshot"]
  snap --> pr["In một dòng ok"]
  kind -->|điều khiển| q{"Queue còn chỗ?"}
  q -->|không| full["err queue"]
  q -->|có| push["Đẩy command_t, in ok queued"]
  kind -->|debug| ses{"debug đang bật?"}
  ses -->|không| no["err debug"]
  ses -->|có| box["Ghi debug_ctrl, in ok"]
  push --> tick["Nhịp 10 ms lấy một lệnh"]
  box --> tick
  tick --> pipe["Chính sách rồi ống cổng ra"]
  pipe --> evt["evt ... khi trạng thái đổi"]
```

`arm`, `disarm`, `ride`, `dismiss`, `aux` đi vào cùng queue dài 4 với BLE. Một nhịp lấy một lệnh. Hàng đầy thì lệnh mới bị bỏ và console in `err queue` ngay, không chờ.

`hold` và `inject` ghi struct `debug_ctrl` trong RAM. Nhịp sau chép struct đó cùng lúc với perception. Tắt `debug` hoặc reset thì struct về rỗng. Reset không phải deep sleep cũng tắt arm, như mục 8.3.

## 9.2 Cú pháp và câu trả lời

Một dòng tối đa 80 byte, kết thúc bằng LF. Token cách nhau bởi một dấu cách, chữ thường, số thập phân. Không có dấu phẩy, không có chuỗi trong ngoặc.

Mỗi lệnh nhận đúng một dòng trả lời ngay:

| Dòng | Nghĩa |
| --- | --- |
| `ok` | Đã ghi nhận |
| `ok queued` | Đã vào queue, chưa phải đã đổi mode |
| `ok k=v k=v` | Kết quả đọc |
| `err syntax` | Thiếu token hoặc thừa token |
| `err range` | Số ngoài khoảng cho phép |
| `err debug` | Lệnh cần phiên debug mà phiên đang tắt |
| `err queue` | Queue đầy, lệnh không vào |
| `err nvs` | Ghi NVS thất bại |

Khi nhịp 10 ms thực sự đổi trạng thái, console in thêm một dòng `evt`, không thay dòng `ok`:

| evt | Khi |
| --- | --- |
| `evt arm=1` / `evt arm=0` | Arm đổi |
| `evt mode=parking` / `riding` / `alarm` | Mode đổi |
| `evt reject=<lệnh> <lý do>` | Lệnh bị mục 8.6 bỏ. Lý do là `mode` |
| `evt fault=1` / `evt fault=0` | `fault_latch` đổi |
| `evt inhibit=<mã>` | Lý do cấm tải đổi |
| `evt sleep=start` / `abort` / `enter` | Giao dịch ngủ |
| `evt hold=off` | Hết hạn giữ kênh |

Mã `inhibit`: `none`, `disarmed`, `power`, `uvlo`, `oc`, `fault`.

`firmware/tools/bringup_log.py` gửi đúng các dòng này và chỉ cần hiểu `ok`, `err`, `evt`.

## 9.3 Lệnh xem

Các lệnh này không cần `debug` và không vào queue.

| Lệnh | In ra | Dùng khi |
| --- | --- | --- |
| `help` | Danh sách lệnh, một lệnh một dòng `ok cmd=...` | Quên cú pháp |
| `status` | mode, armed, fault, uvlo, inhibit, debug, v, i, lux, range, motion | Nhìn một nhịp |
| `inputs` | raw và stable của sáu công tắc, kèm hazard | Soát debounce 30 ms |
| `sense` | bốn địa chỉ I2C còn sống, tuổi mẫu lux/range/power, gps_fix | Biết mẫu nào hết hạn |
| `power` | bus_mv, current_ma, power_dw, energy_mwh, power_valid | Đối chiếu INA228 |
| `gates` | duty và mức boolean muốn, rồi mức đã ghi ra chân | Thấy chốt arm và luật còi |
| `faults` | fault_latch, uvlo_count, cmd_dropped, failsafe_count, motion_fault, horn_lockout | Đếm lỗi |
| `config` | Mọi hằng RAM mục 8.2 | Xác nhận số đang dùng |
| `snapshot` | 32 byte BLE, hex liền | So với notify điện thoại |
| `watch <ms>` | Lặp `status` mỗi ms | Theo dõi liên tục |
| `watch off` | Dừng lặp | |

`watch` nhận 100 đến 5000. Task `console` tự in, nhịp 10 ms không gọi `printf`. `inputs` in cả `raw` và `stable` để thấy rung dưới 30 ms không đổi `stable`.

`gates` in hai lớp: `want_*` trước ống cổng ra và `out_*` sau ống. Bring-up chưa arm thì `want_head` có thể khác 0 trong khi `out_head` bằng 0.

## 9.4 Lệnh điều khiển

Cùng nghĩa với opcode BLE. Không cần phiên debug.

| Lệnh | Opcode | Việc của nhịp 10 ms |
| --- | --- | --- |
| `arm` | `0x03` | Bật arm, xóa `fault_latch`, ghi RTC |
| `disarm` | `0x04` | Tắt arm, xóa fault, xóa AUX, xóa khóa còi |
| `ride start` | `0x01` | `PARKING` sang `RIDING`. Mode khác thì `evt reject=ride_start mode` |
| `ride stop` | `0x02` | `RIDING` sang `PARKING`. Mode khác thì reject |
| `dismiss` | `0x05` | Trong `ALARM` thì về `PARKING`. Luôn xóa `fault_latch` |
| `aux on` | `0x06` | Chốt AUX |
| `aux off` | `0x07` | Nhả AUX |

`ok queued` chỉ nghĩa là hàng đã nhận. Mode mới nằm ở dòng `evt` của nhịp sau. Gõ `arm` rồi `ride start` trên hai dòng thì đúng luật một lệnh mỗi nhịp: arm trước, sang `RIDING` ở nhịp kế.

## 9.5 Phiên debug

`debug on` mở phiên trong RAM. `debug off` và mọi reset đều đóng phiên, xóa `hold` và `inject`. Phiên không ghi NVS, không sống qua deep sleep.

Lệnh mục 9.6 và 9.7 khi phiên tắt trả `err debug` và không ghi gì.

`debug` không in thêm. `status` có trường `debug=0|1`.

## 9.6 Giữ một kênh tải

Dùng khi đo dòng từng tải trên nguồn J1, đúng bước gắn từng tải một của bring-up.

| Lệnh | Tác dụng |
| --- | --- |
| `hold head on` | Ép duty pha = 1023 |
| `hold head <0..1023>` | Ép đúng duty |
| `hold head off` | Ép duty pha = 0 |
| `hold tail on\|off\|<duty>` | Đèn hậu |
| `hold left on` | `left_lit` true, duty vẫn theo pha 800 ms |
| `hold left off` | Duty trái = 0 và `left_lit` false |
| `hold left <0..1023>` | Ép đúng duty, không nhấp. `left_lit` true khi duty khác 0 |
| `hold right ...` | Cùng luật với trái |
| `hold brake on\|off` | GPIO phanh. Có duty thì `err syntax` |
| `hold horn on\|off` | GPIO còi người lái |
| `hold aux on\|off` | GPIO AUX |
| `hold off` | Xóa mọi ép kênh |

`hold horn on 500` thừa token, trả `err syntax`, không ép một nửa.

Kênh không bị `hold` vẫn do chính sách tính. Sau khi trộn, ống cổng ra chạy nguyên: chưa arm thì mọi chân vẫn thấp, mất số đo nguồn thì thấp, UVLO và quá dòng vẫn khóa, còi người lái vẫn chịu luật 30 s và luật chưa biết dòng còi. `hold` không tắt các luật đó.

Mỗi kênh đang giữ hết hạn sau 30 s rồi tự nhả, in `evt hold=off`. Muốn giữ lâu hơn thì gõ lại lệnh. Còi vì vậy không kêu mãi nếu cáp USB tuột giữa chừng.

`hold left on` và `hold right on` đi theo pha xi-nhan, nên nửa kỳ tắt vẫn có `left_lit` true. Số duty cố định chỉ dùng khi đo dòng, và lúc đó kênh không nhấp. Luật còi đọc cờ `lit`, không đọc duty tức thời.

## 9.7 Bơm đầu vào

Bơm thay giá trị mà chính sách và mode đọc. Không thay số đo nguồn. Áp và dòng trong ống cổng ra luôn là số của INA228.

| Lệnh | Khoảng | Thay cho |
| --- | --- | --- |
| `inject lux <0..65535>` | lux | BH1750 trong luật đèn pha |
| `inject lux off` | | Trả lux về cảm biến |
| `inject motion on` | | `motion` thô |
| `inject motion off` | | `motion` thô false |
| `inject clear motion` | | Trả chuyển động về IMU |
| `inject range <0..65534>` | mm | Khoảng cách LiDAR |
| `inject range off` | | Trả về cảm biến |
| `inject pin low` | | Chỉ vị từ “chân IMU thấp” trong luật xin ngủ |
| `inject pin high` | | Cấm xin ngủ theo luật phần mềm |
| `inject pin off` | | Trả về GPIO38 thật |
| `inject off` | | Xóa mọi bơm |

`inject range 65535` bị `err range` vì `0xFFFF` là mã không có mẫu. `inject range 0` hợp lệ và phải làm `obstacle` true. `inject range 4000` phải làm `obstacle` false.

`inject pin` không đụng `esp_sleep_enable_ext0_wakeup`. Chân thật vẫn là nguồn thức. Bơm `pin low` chỉ để đi hết giao dịch ngủ trên bàn khi chân đang cao. Nếu chân thật vẫn cao, chip sẽ thức lại ngay; `status` sau boot cho thấy reset deep sleep và arm còn hay không.

`sense` in cả giá trị cảm biến và giá trị sau bơm, với cờ `inj=lux` khi bơm còn hiệu lực. Người test không tưởng nhầm lux bơm là lux đo được.

## 9.8 Sửa hằng trong RAM

`config set <tên> <số>` sửa bản RAM. Nhịp sau dùng số mới. `config save <tên>` chỉ có với hai tên được ghi NVS, và ghi đó chạy trên task `console`.

| Tên | Khoảng | Cần debug | Được save |
| --- | --- | --- | --- |
| `horn_current_ma` | 0..5000, 0 là chưa biết | không | có |
| `shunt_cal` | 1..65535 | không | có |
| `stop_idle_s` | 5..3600 | có | không |
| `sleep_after_s` | 5..3600 | có | không |
| `alarm_s` | 1..120 | có | không |
| `alarm_gap_s` | 0..60 | có | không |
| `alarm_motion_ms` | 50..5000 | có | không |
| `debounce_ms` | 0..500 | có | không |
| `oc_ma` | 100..2500 | có | không |
| `uvlo_mv` | 3000..4500 | có | không |

`oc_ma` không đặt được trên 2500. `failsafe_ms` không có trong bảng. Reset đưa các tên không save về mặc định mục 8.2. `horn_current_ma` và `shunt_cal` đã save thì nạp lại từ NVS lúc boot.

`config set oc_ma 3000` trả `err range` và giữ số cũ.

## 9.9 Ngủ và quét bus

| Lệnh | Đường | Việc |
| --- | --- | --- |
| `sleep` | queue, cần debug | Nhịp sau xin ngủ nếu đang `PARKING`, đang yên, và vị từ chân IMU cho phép. Thiếu điều kiện thì `evt sleep=abort` kèm lý do `mode`, `motion` hoặc `pin` |
| `i2c` | cờ cho task `sensors` | Quét lại bus, in `ok addr=40,23,29,68` hoặc địa chỉ thiếu |

`i2c` không quét trên task console. Task `sensors` quét ở vòng của nó rồi console in kết quả. Quét trùng với giao dịch đang chạy thì vòng đó hoãn quét một nhịp, không chen giữa một lần đọc INA228.

## 9.10 Kịch bản gõ tay

Mỗi kịch bản giả định dòng `ok` đã về trước khi gõ dòng tiếp. Nguồn tải là J1 khi có lệnh `hold` hoặc `arm` mà công tắc đang bấm. Trên chỉ USB, arm vẫn bật được cờ nhưng ống cổng ra cấm tải nếu dòng tổng kéo sụt áp hoặc chạm ngưỡng quá dòng.

**Gate lúc boot.** `status` rồi `gates`. Kỳ vọng `armed=0`, `inhibit=disarmed`, mọi `out_*=0`.

**Debounce.** `watch 100`, bấm rồi thả từng công tắc. `raw` đổi ngay, `stable` đổi khi đủ `debounce_ms`. Rung nhanh hơn 30 ms thì `stable` đứng yên. `watch off`.

**Hazard.** Giữ trái và phải. `inputs` có `hazard=1`. Chỉ giữ trái thì `hazard=0` và `stable_right=0`.

**Arm không sống qua USB reset.** `arm`, thấy `evt arm=1`, nhấn reset. `status` có `armed=0`.

**Một tải.** Nguồn J1. `arm`, `debug on`, `hold head on`, đo dòng, `hold off`. Lặp `tail`, `left`, `right`, `brake`, `horn`, `aux`. Giữa hai kênh là `hold off`.

**Đèn pha.** `debug on`, `inject lux 99` thì `gates` có `want_head=1023` sau khi arm. `inject lux 100` giữ nguyên. `inject lux 201` thì `want_head=0`. `inject lux off` trả về cảm biến. Bấm `LIGHT_SW` trong lúc `inject lux 201` thì `want_head=1023`, thả thì về 0.

**Xi-nhan và luật còi.** `config set horn_current_ma 0` nếu đang khác 0. `arm`, `debug on`, `hold head on`, `hold tail on`, `hold left on`, `hold horn on`. Trái vẫn nhấp. `out_horn=0` cả ở nửa kỳ duty trái bằng 0. `hold left off` thì `out_horn` được phép lên 1. `config set horn_current_ma 800` rồi `config save horn_current_ma` khi đã đo dòng còi thật, luật cấm này hết hiệu lực.

**Còi 30 s.** `hold horn on`, chờ `evt hold=off`. Thả công tắc vật lý nếu đang kẹt, rồi `hold horn on` lại được.

**Quá dòng và khóa.** `debug on`, `config set oc_ma 100`, `arm`, `hold head on` với một tải nhỏ hơn cầu chì nhưng hơn 100 mA. Kỳ vọng `evt fault=1`, `out_*=0`. `hold head on` lần nữa không sáng cho đến `dismiss` hoặc `arm`. `config` sau reset hết `oc_ma` đã hạ.

**Mất số đo nguồn.** Rút tạm module hoặc để mẫu quá 200 ms trên bàn có kẹp. `inhibit=power`, mọi `out_*=0` dù `armed=1`.

**Mode.** `config set stop_idle_s 5` trong phiên debug. `ride start` chỉ từ `PARKING`. `inject motion on` rồi `ride start`: ở `RIDING` và không sang `ALARM`. `inject motion off`, sau 5 s có `evt mode=parking`. `ride start` lúc `mode=alarm` ra `evt reject=ride_start mode`.

**Báo động lặp.** `config set alarm_s 2`, `config set alarm_gap_s 5`, `config set alarm_motion_ms 400`. Về `PARKING`, `inject motion on`. Vào `ALARM` khoảng 400 ms, hết 2 s thì về `PARKING`, khoảng 5 s sau vào `ALARM` lại nếu bơm còn `on`.

**LiDAR không phanh.** `inject range 3999`. `status` có cờ vật cản, `out_brake` không đổi theo range. `inject range 4000` thì cờ tắt.

**Ngủ.** `config set sleep_after_s 5`, `inject motion off`, `inject pin low`, `sleep`. Có `evt sleep=enter` khi đủ yên. `inject motion on` trong lúc chờ thì `evt sleep=abort`.

**Hàng lệnh.** Không có lệnh riêng để làm đầy hàng. Bốn lệnh BLE viết dồn trong một nhịp 10 ms, lệnh thứ năm trên console trả `err queue`, bốn lệnh cũ vẫn chạy đúng thứ tự.

## 9.11 Việc console không làm

- Không ghi gate từ task `console`.
- Không bơm áp hoặc dòng để vượt ống cổng ra.
- Không đặt `failsafe_ms`, không tắt watchdog.
- Không ghi NVS ngoài `horn_current_ma` và `shunt_cal`.
- Không thêm opcode BLE. Điện thoại vẫn chỉ có bảy lệnh mục 6.10.

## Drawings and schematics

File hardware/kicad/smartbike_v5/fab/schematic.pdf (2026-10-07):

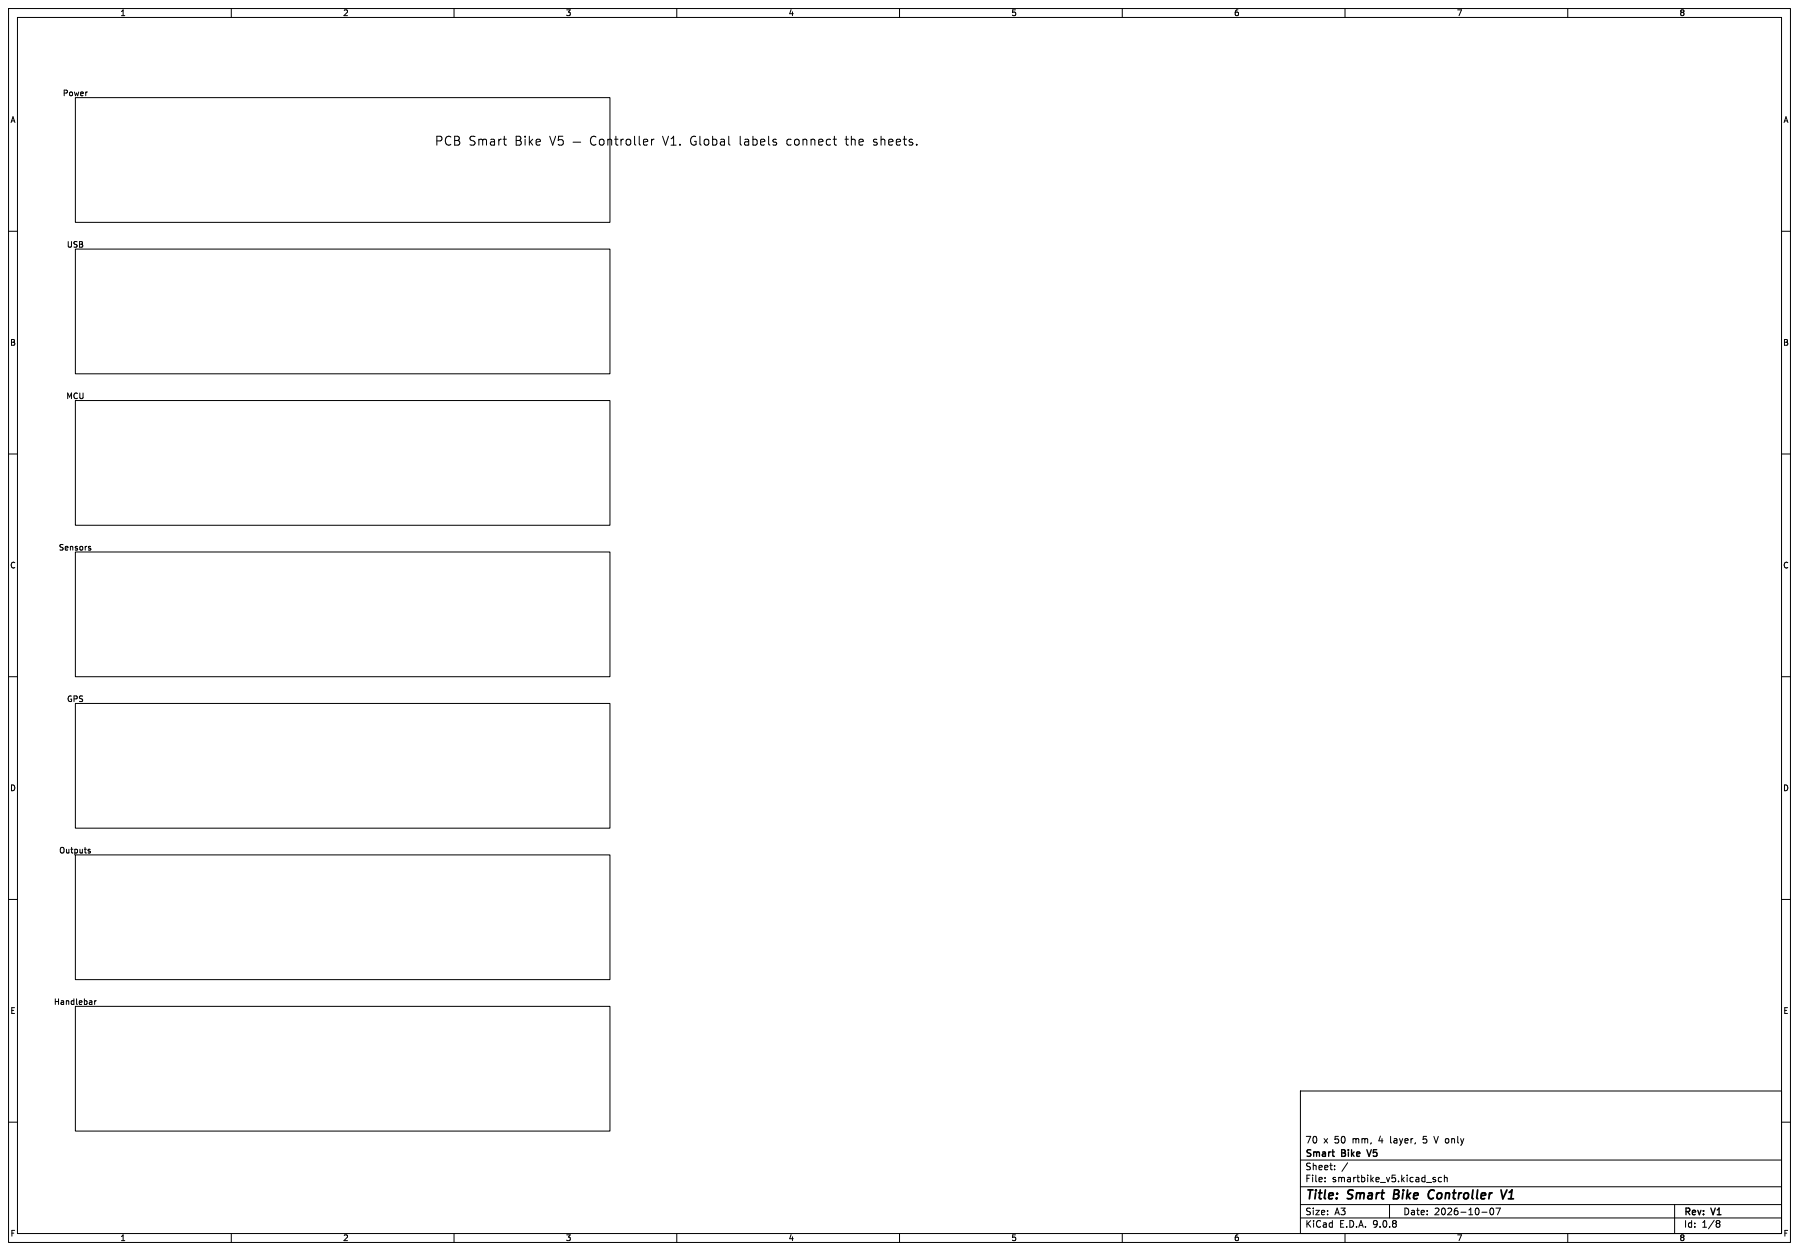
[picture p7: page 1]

Sensors GPS Outputs Handlebar

Id: 1/8 Title: Smart Bike Controller V1

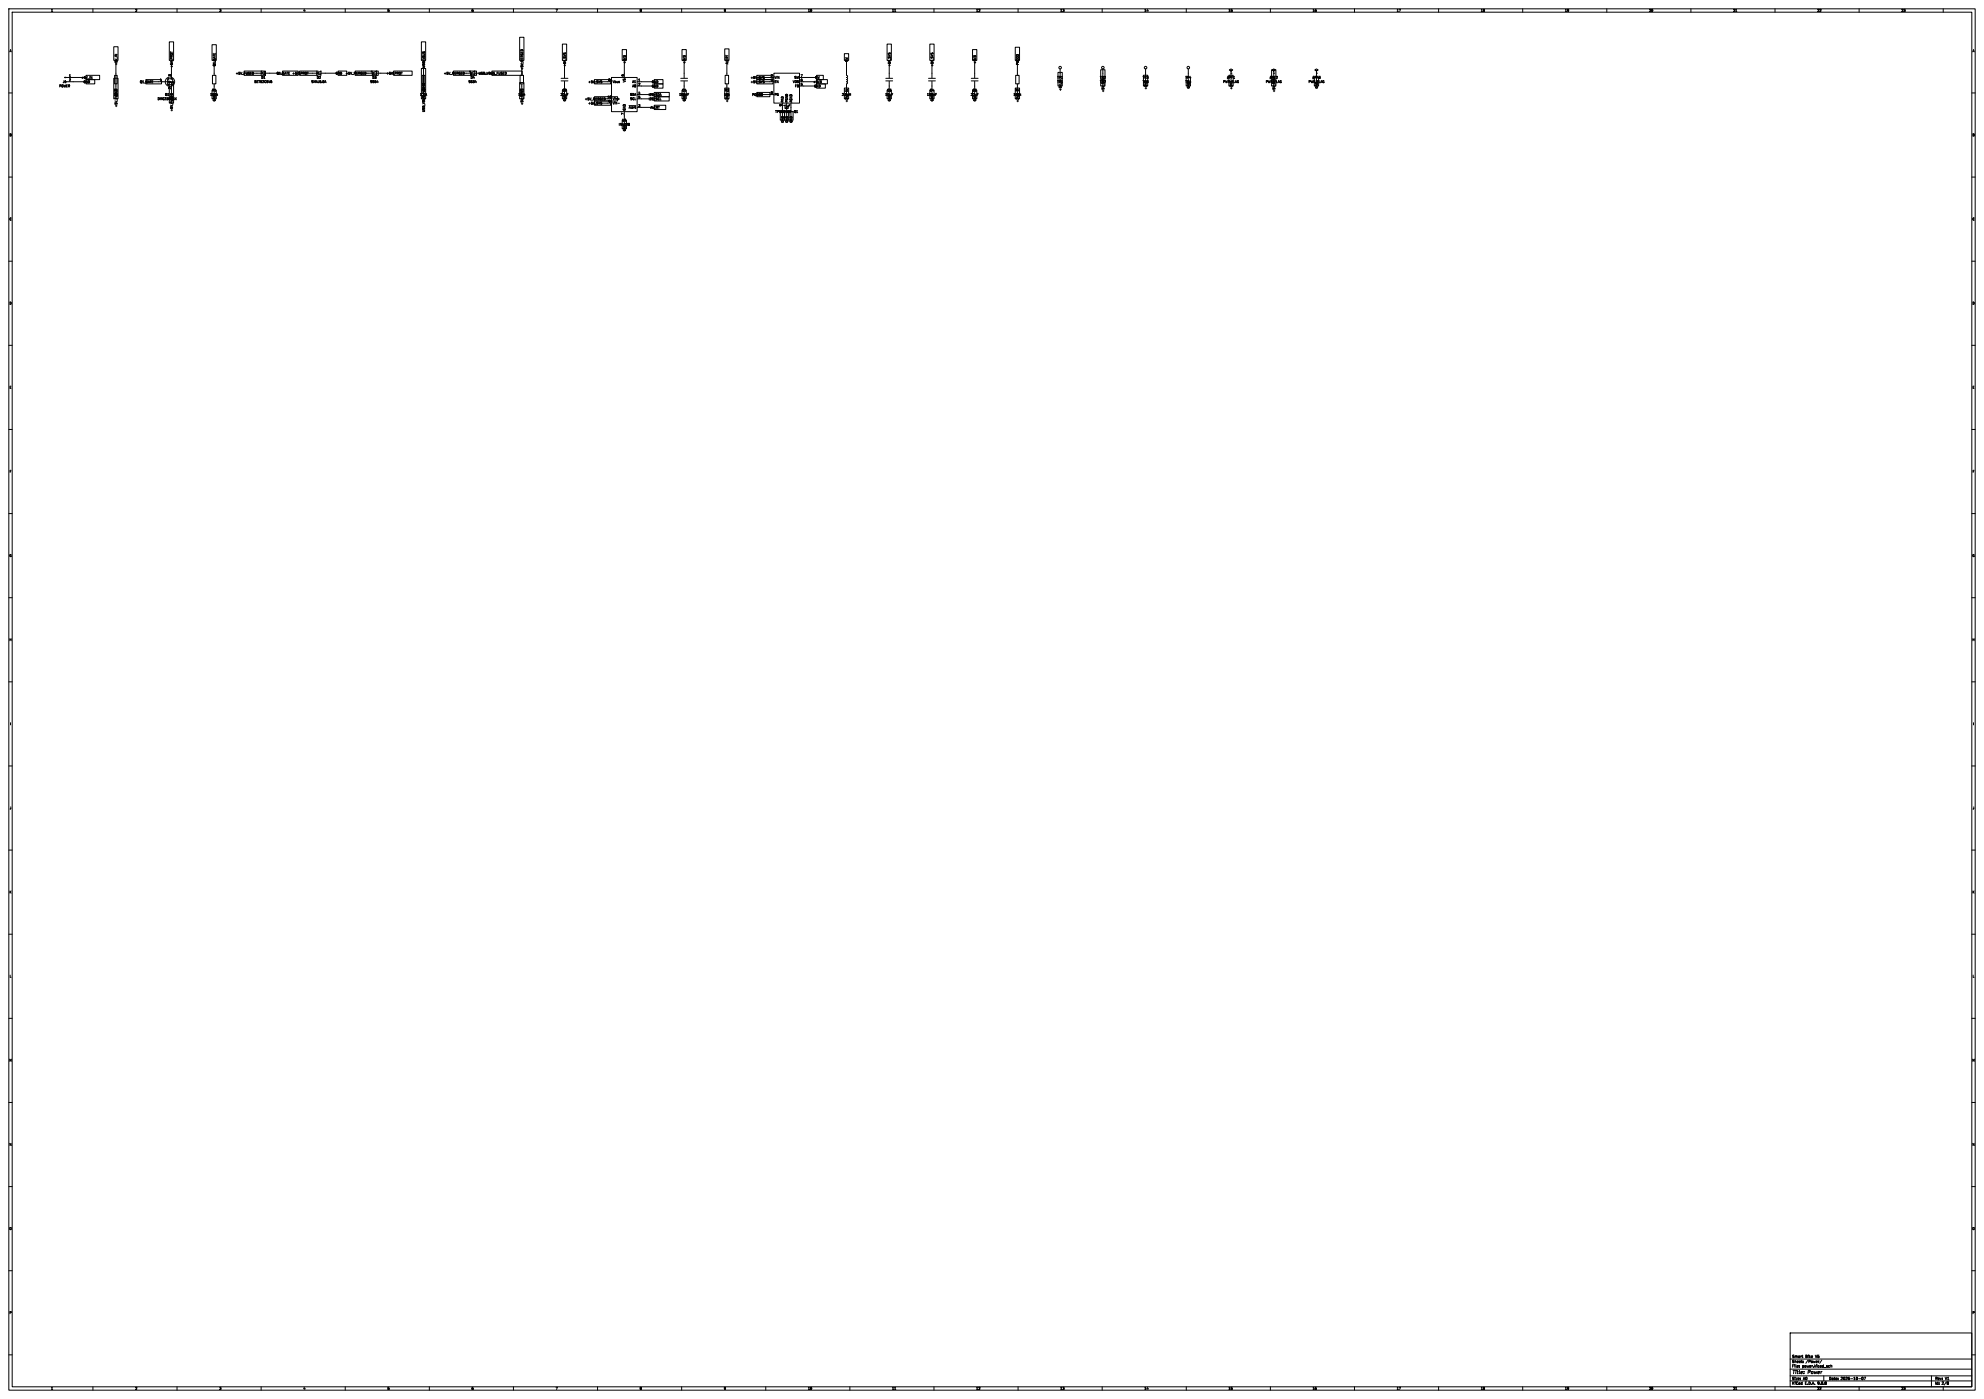
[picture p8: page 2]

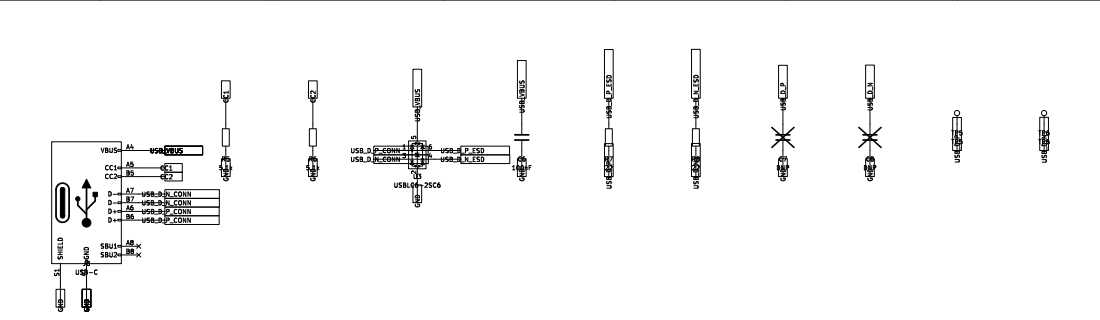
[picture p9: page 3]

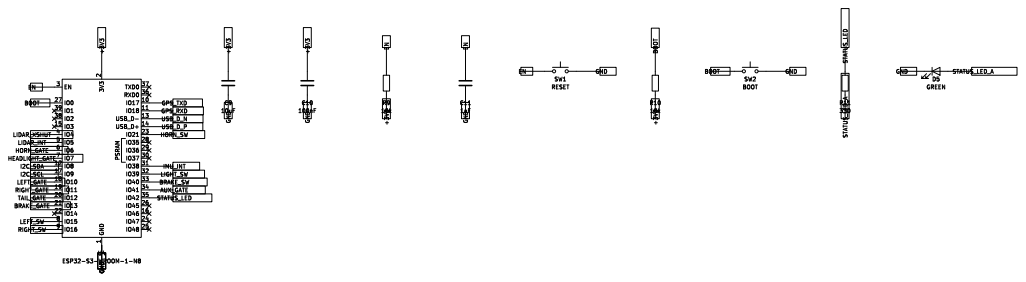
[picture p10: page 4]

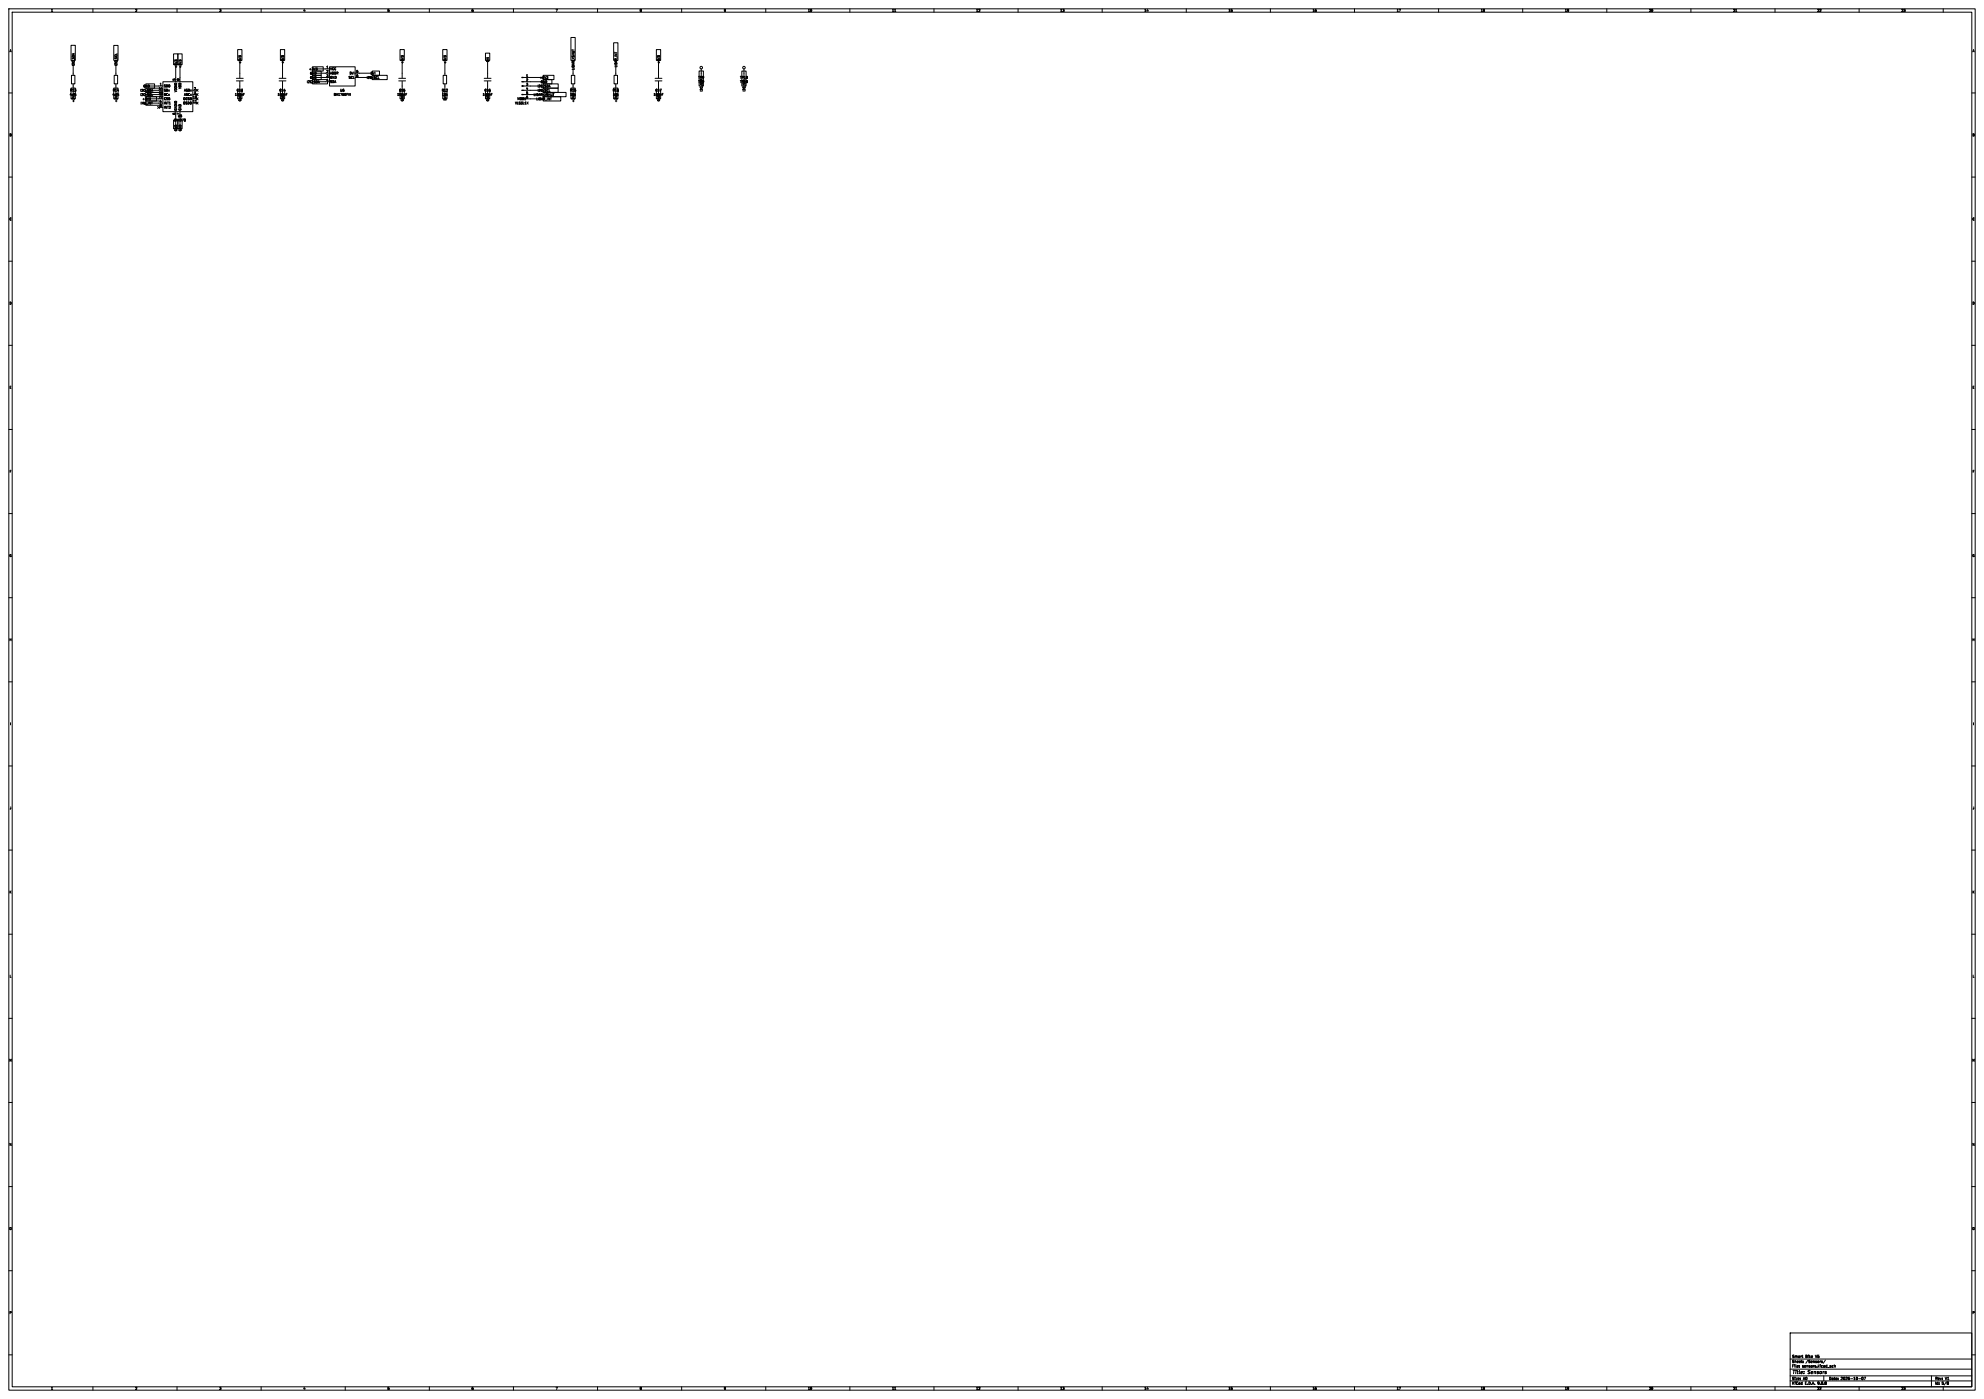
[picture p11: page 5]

7 ASDx 2 ASCx 3 OCSB 10 OSDO 11 U5 BMI270 VCC 1 ADDR 2 GND 3 SDA 4 DVI 5 SCL 6 U6 BH1750FVI R13

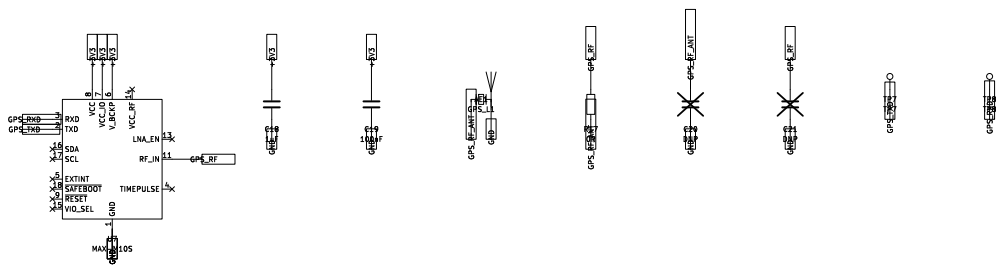
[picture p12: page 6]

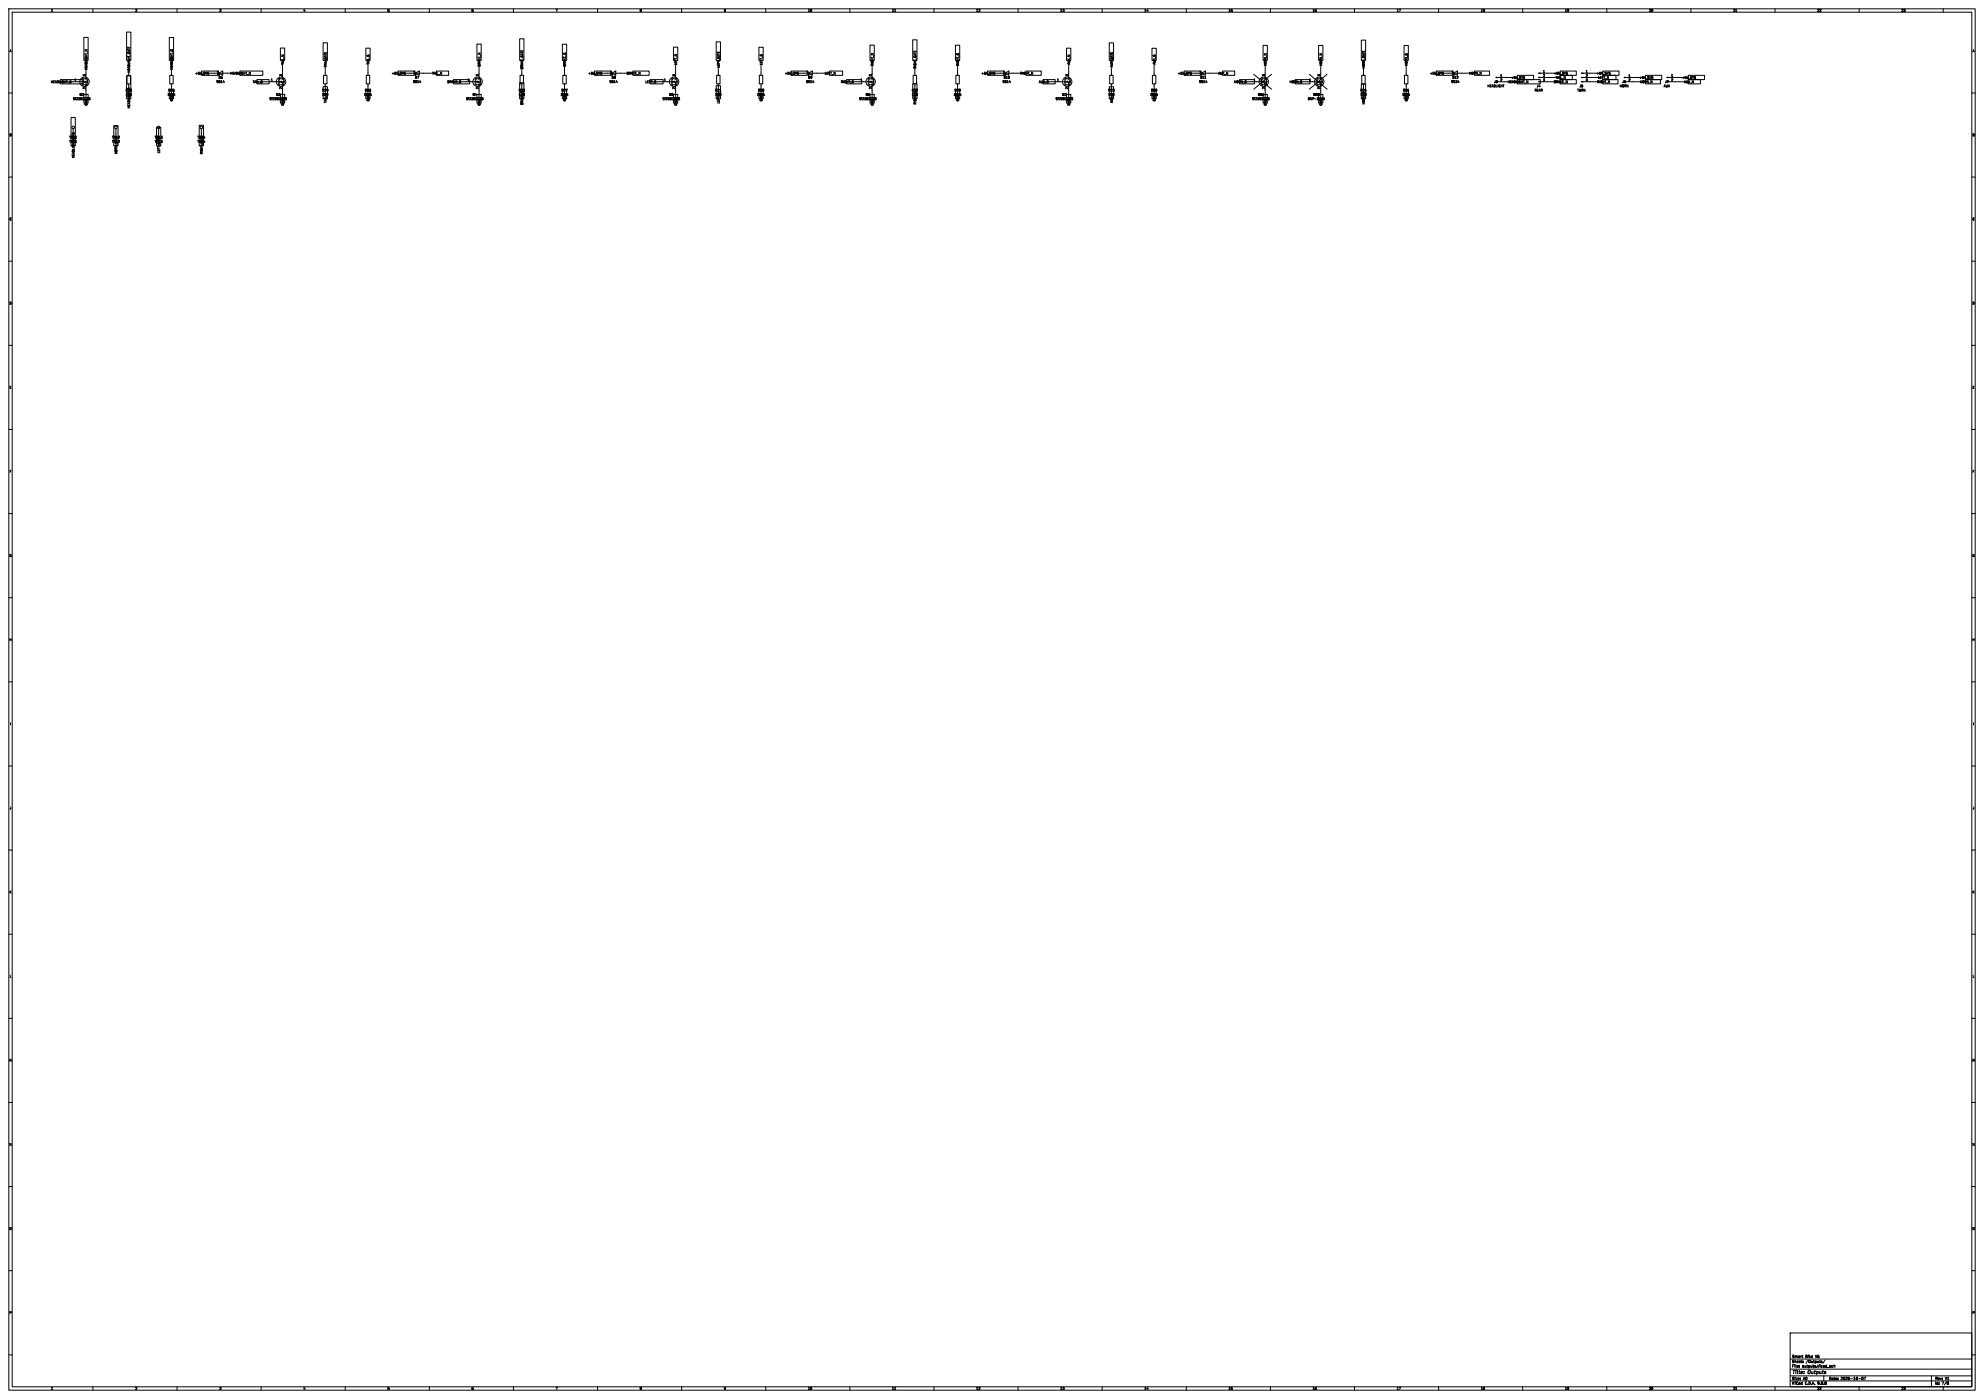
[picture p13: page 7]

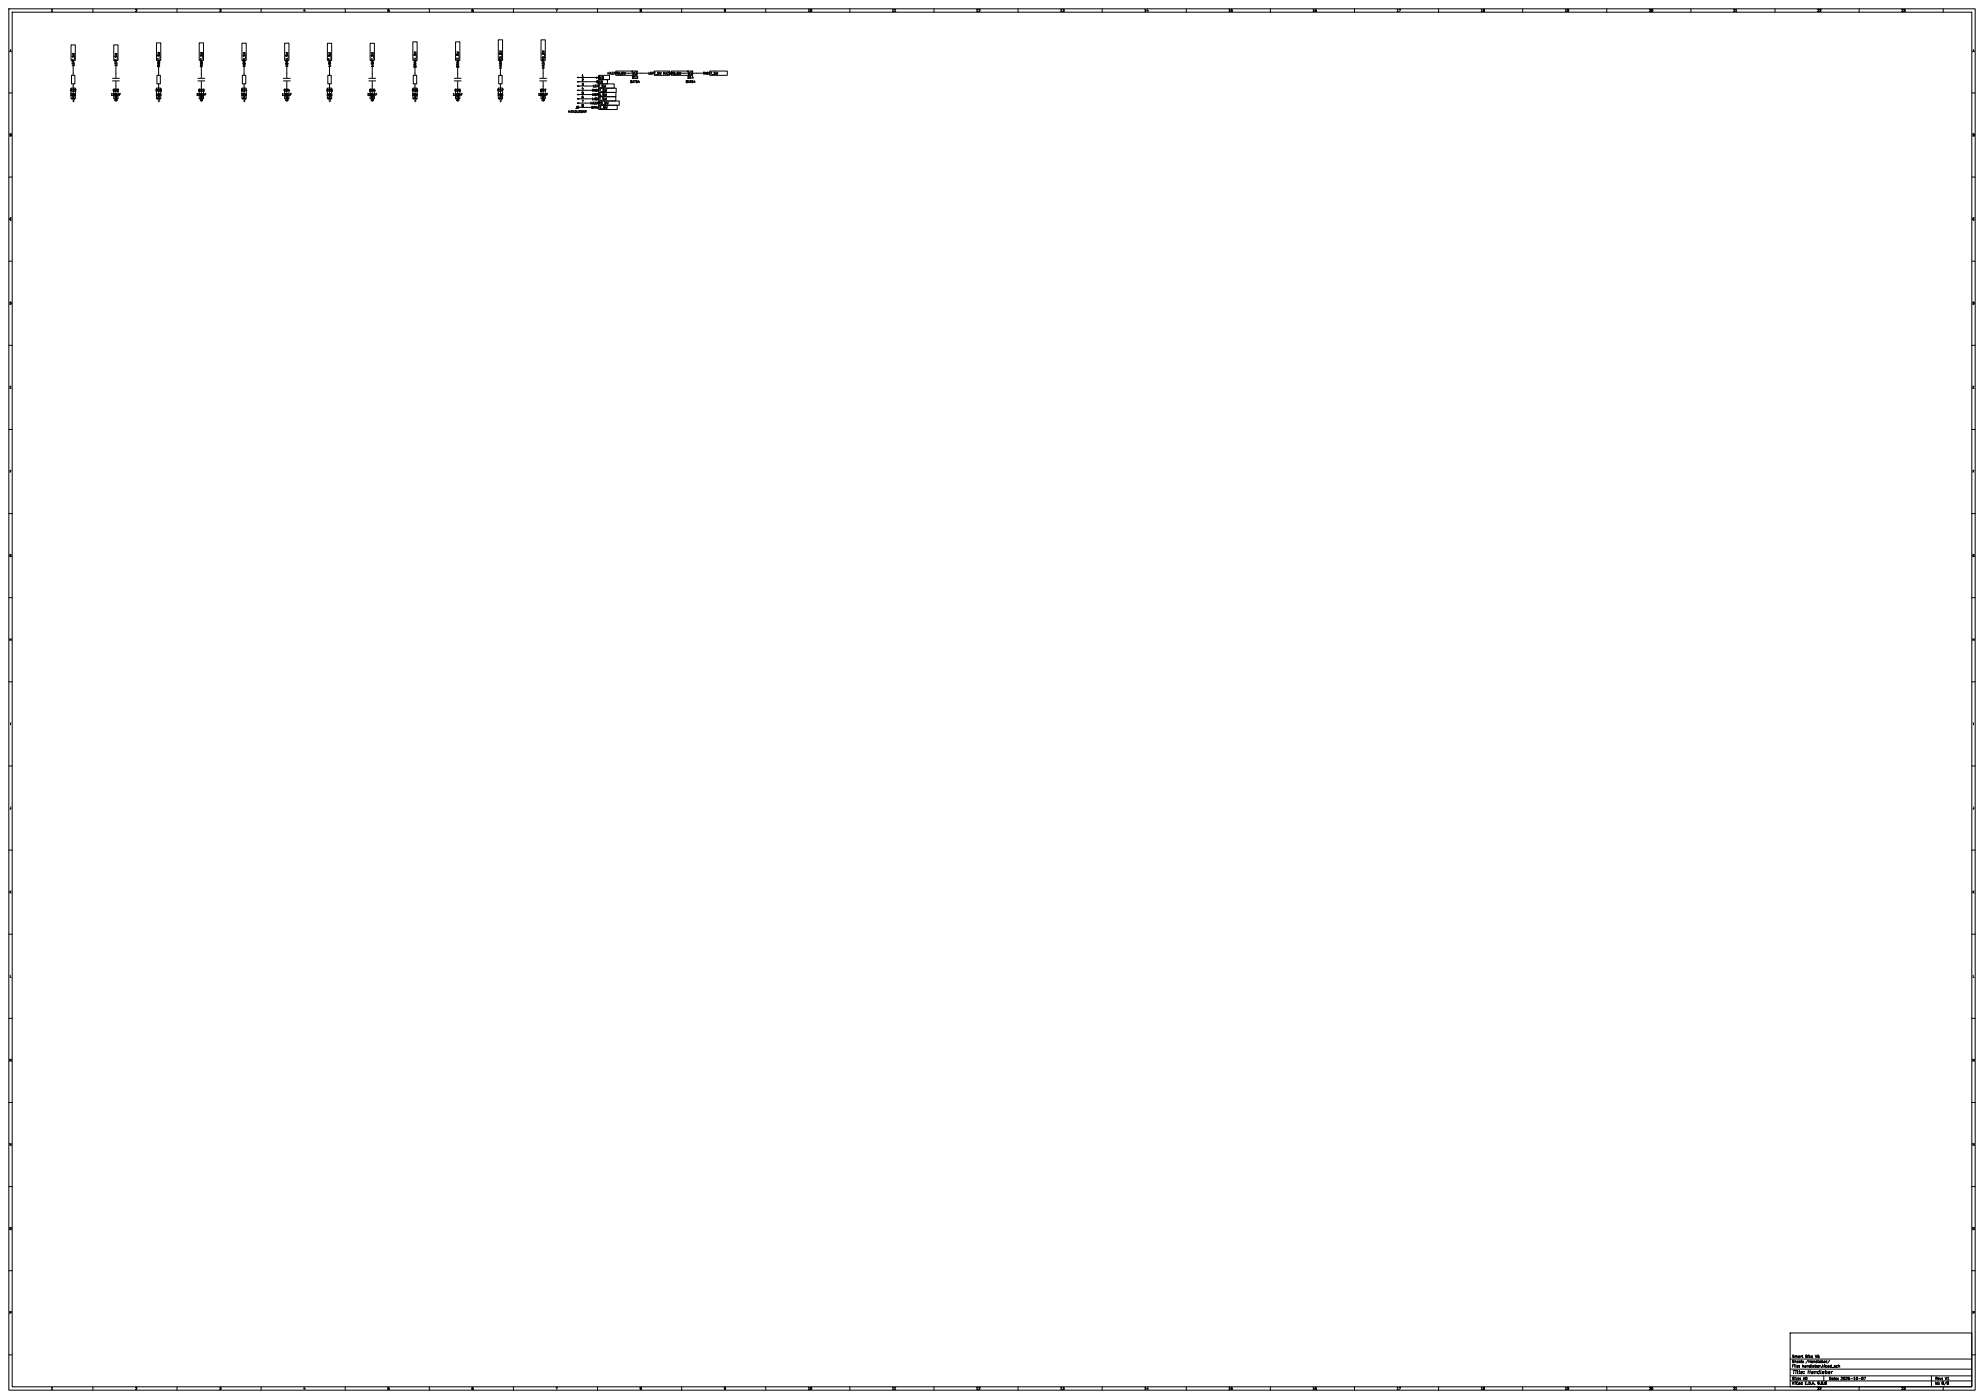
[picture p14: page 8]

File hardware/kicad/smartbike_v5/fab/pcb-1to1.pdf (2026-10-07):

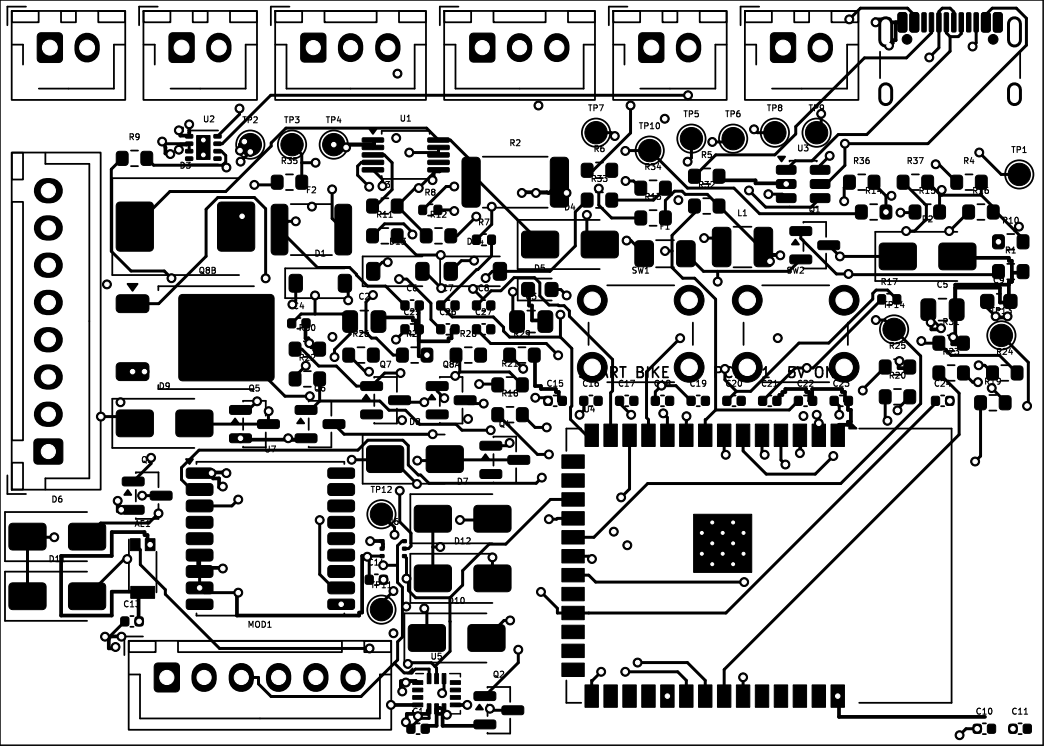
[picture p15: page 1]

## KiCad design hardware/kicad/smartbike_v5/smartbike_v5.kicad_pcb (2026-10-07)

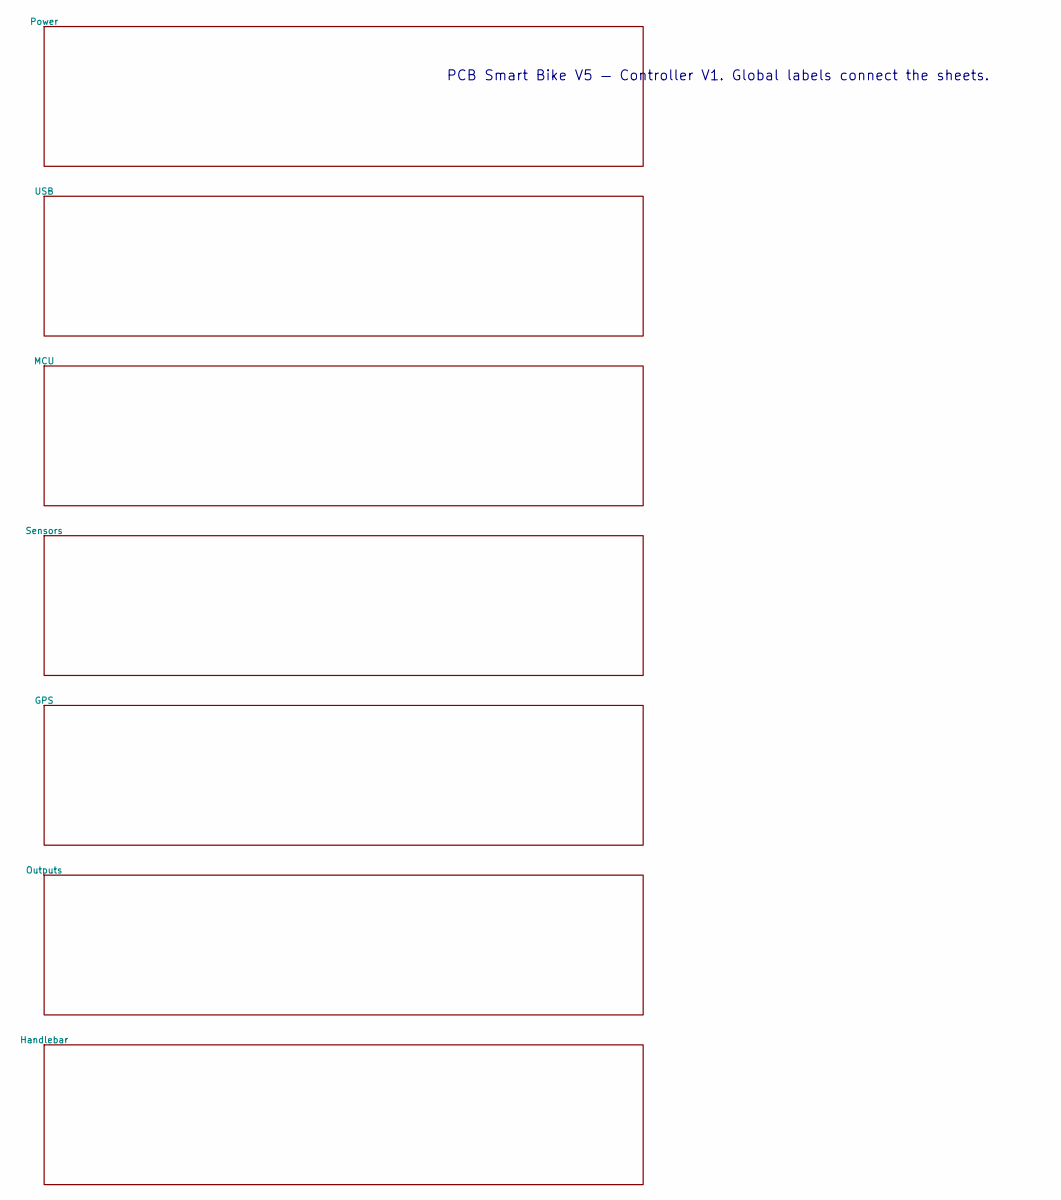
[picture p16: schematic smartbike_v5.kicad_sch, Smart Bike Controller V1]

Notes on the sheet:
PCB Smart Bike V5 — Controller V1. Global labels connect the sheets.

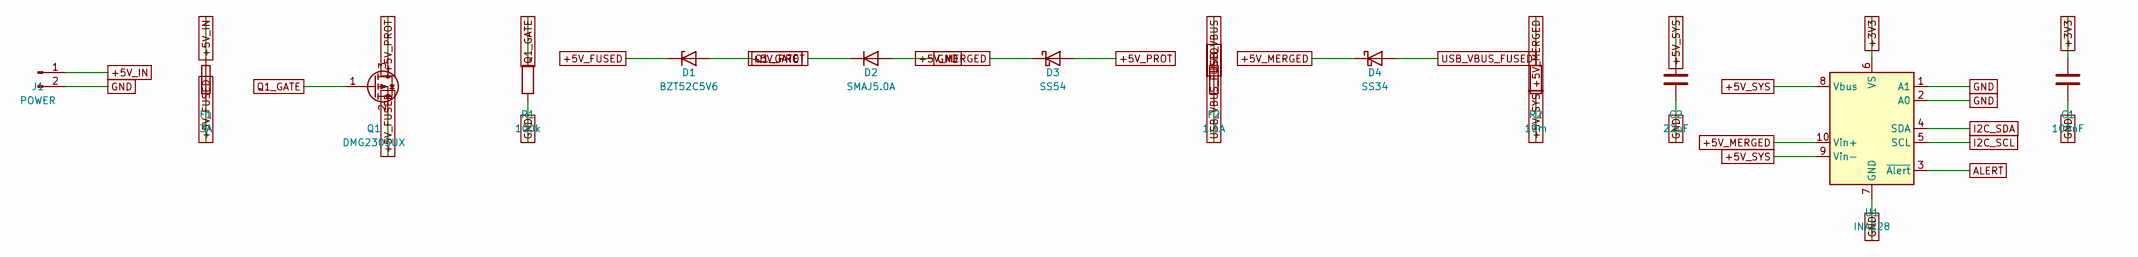
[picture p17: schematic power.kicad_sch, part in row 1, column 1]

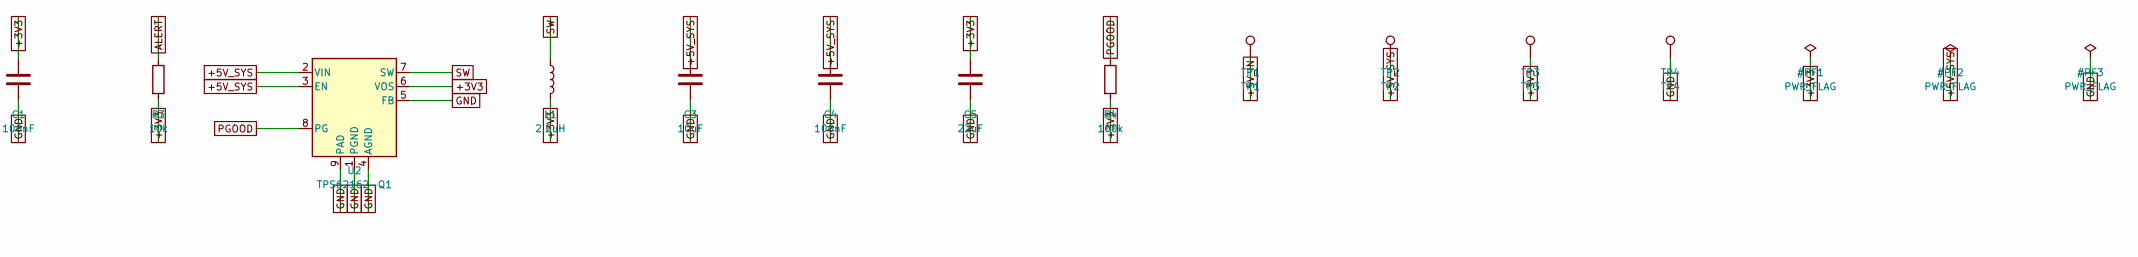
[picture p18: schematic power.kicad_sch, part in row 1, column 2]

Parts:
C1, C4: 100nF; C_0402_1005Metric
C2, C5: 22uF; C_0805_2012Metric
C3: 10uF; C_0805_2012Metric
D1: BZT52C5V6; D_SOD-123
D2: SMAJ5.0A; D_SMA
D3: SS54; D_SMC
D4: SS34; D_SMA
F1: 3A; Fuse_1206_3216Metric
F2: 1.1A; Fuse_1812_4532Metric
J1: POWER; JST_XH_B2B-XH-AM_1x02_P2.50mm_Vertical
L1: 2.2uH; L_1210_3225Metric
Q1: DMG2305UX; SOT-23
R1, R4: 100k; R_0603_1608Metric
R2: 10m; R_2512_6332Metric
R3: 10k; R_0603_1608Metric
TP1: TP1; TestPoint_Pad_D1.5mm
TP2: TP2; TestPoint_Pad_D1.5mm
TP3: TP3; TestPoint_Pad_D1.5mm
TP4: TP4; TestPoint_Pad_D1.5mm
U1: INA228; VSSOP-10_3x3mm_P0.5mm
U2: TPS62162-Q1; WSON-8-1EP_2x2mm_P0.5mm_EP0.9x1.6mm_ThermalVias

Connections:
+5V_FUSED: D1.1 (K), F1.2, Q1.2 (S)
+5V_IN: F1.1, J1.1, TP1.1
+5V_MERGED: D3.1 (K), D4.1 (K), R2.1, U1.10 (Vin+)
+5V_PROT: D2.1 (K), D3.2 (A), Q1.3 (D)
ALERT: R3.1, U1.3 (~Alert)
I2C_SCL: U1.5 (SCL); also elsewhere on the board
I2C_SDA: U1.4 (SDA); also elsewhere on the board
PGOOD: R4.1, U2.8 (PG)
Q1_GATE: D1.2 (A), Q1.1 (G), R1.1
SW: L1.1, U2.7 (SW)
USB_VBUS: F2.1; also elsewhere on the board
USB_VBUS_FUSED: D4.2 (A), F2.2

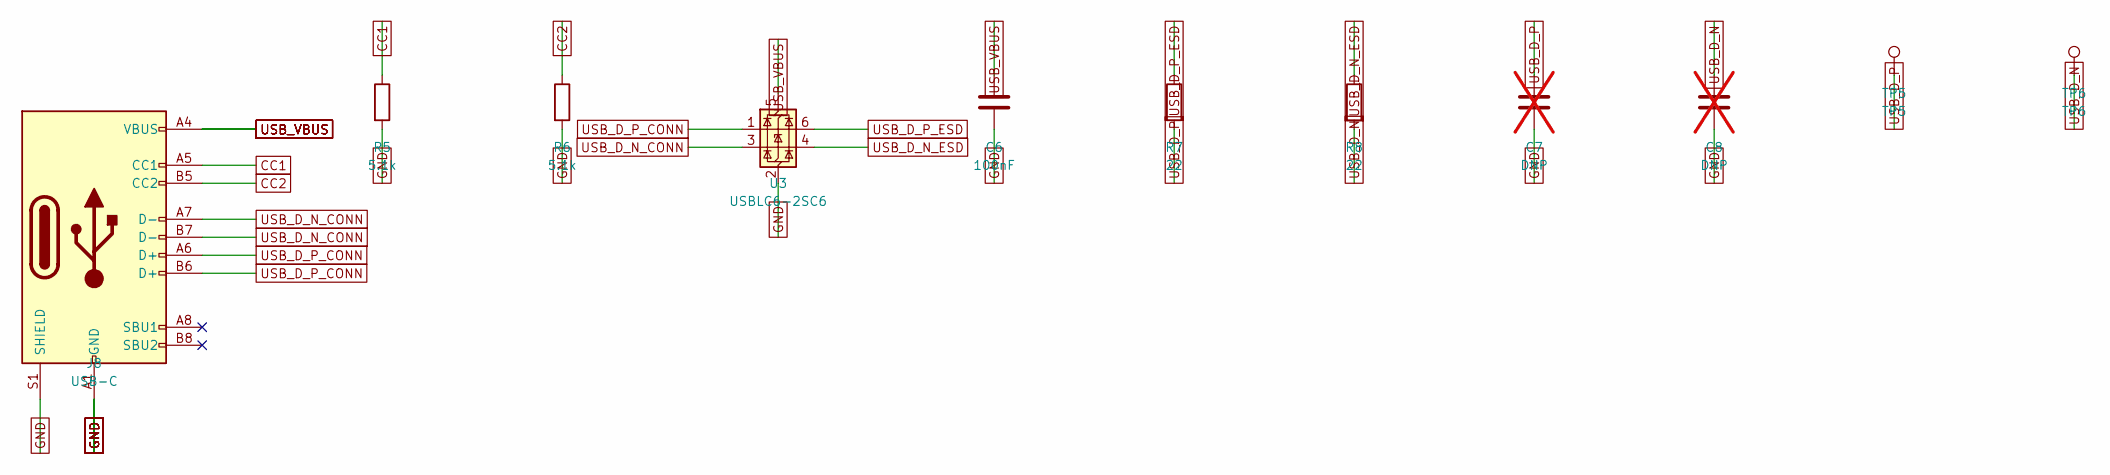
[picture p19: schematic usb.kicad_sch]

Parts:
C6: 100nF; C_0402_1005Metric
C7, C8: DNP; C_0402_1005Metric; not fitted
J8: USB-C; USB_C_Receptacle_HCTL_HC-TYPE-C-16P-01A
R5, R6: 5.1k; R_0603_1608Metric
R7, R8: 22; R_0402_1005Metric
TP5: TP5; TestPoint_Pad_D1.5mm
TP6: TP6; TestPoint_Pad_D1.5mm
U3: USBLC6-2SC6; SOT-23-6

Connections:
CC1: J8.A5 (CC1), R5.1
CC2: J8.B5 (CC2), R6.1
USB_D_N: C8.1, R8.2, TP6.1; also elsewhere on the board
USB_D_N_CONN: J8.A7 (D-), J8.B7 (D-), U3.3 (I/O2)
USB_D_N_ESD: R8.1, U3.4 (I/O2)
USB_D_P: C7.1, R7.2, TP5.1; also elsewhere on the board
USB_D_P_CONN: J8.A6 (D+), J8.B6 (D+), U3.1 (I/O1)
USB_D_P_ESD: R7.1, U3.6 (I/O1)
USB_VBUS: C6.1, J8.A4 (VBUS), J8.A9 (VBUS), J8.B4 (VBUS), J8.B9 (VBUS), U3.5 (VBUS); also elsewhere on the board

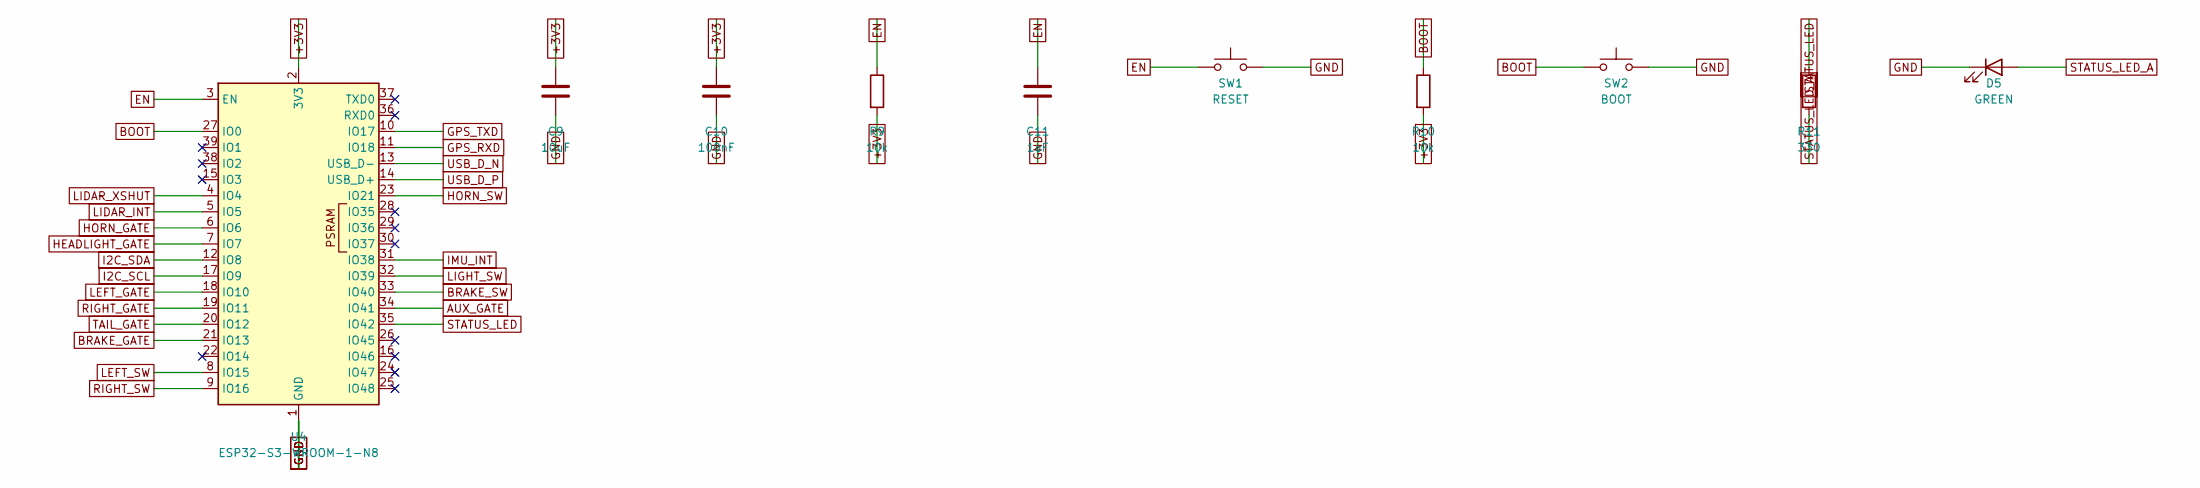
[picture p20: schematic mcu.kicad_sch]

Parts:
C9: 10uF; C_0603_1608Metric
C10: 100nF; C_0402_1005Metric
C11: 1uF; C_0402_1005Metric
D5: GREEN; LED_0603_1608Metric
R9, R10: 10k; R_0603_1608Metric
R11: 330; R_0603_1608Metric
SW1: RESET; SW_PUSH_6mm
SW2: BOOT; SW_PUSH_6mm
U4: ESP32-S3-WROOM-1-N8; ESP32-S3-WROOM-1

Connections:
AUX_GATE: U4.34 (IO41); also elsewhere on the board
BOOT: R10.1, SW2.1, U4.27 (IO0)
BRAKE_GATE: U4.21 (IO13); also elsewhere on the board
BRAKE_SW: U4.33 (IO40); also elsewhere on the board
EN: C11.1, R9.1, SW1.1, U4.3 (EN)
GPS_RXD: U4.11 (IO18); also elsewhere on the board
GPS_TXD: U4.10 (IO17); also elsewhere on the board
HEADLIGHT_GATE: U4.7 (IO7); also elsewhere on the board
HORN_GATE: U4.6 (IO6); also elsewhere on the board
HORN_SW: U4.23 (IO21); also elsewhere on the board
I2C_SCL: U4.17 (IO9); also elsewhere on the board
I2C_SDA: U4.12 (IO8); also elsewhere on the board
IMU_INT: U4.31 (IO38); also elsewhere on the board
LEFT_GATE: U4.18 (IO10); also elsewhere on the board
LEFT_SW: U4.8 (IO15); also elsewhere on the board
LIDAR_INT: U4.5 (IO5); also elsewhere on the board
LIDAR_XSHUT: U4.4 (IO4); also elsewhere on the board
LIGHT_SW: U4.32 (IO39); also elsewhere on the board
RIGHT_GATE: U4.19 (IO11); also elsewhere on the board
RIGHT_SW: U4.9 (IO16); also elsewhere on the board
STATUS_LED: R11.1, U4.35 (IO42)
STATUS_LED_A: D5.2 (A), R11.2
TAIL_GATE: U4.20 (IO12); also elsewhere on the board
USB_D_N: U4.13 (USB_D-); also elsewhere on the board
USB_D_P: U4.14 (USB_D+); also elsewhere on the board

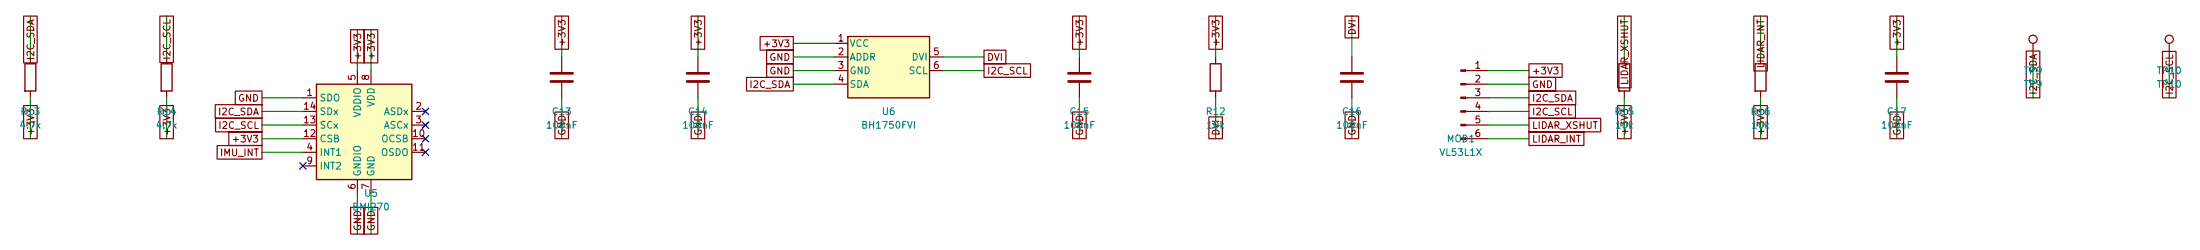
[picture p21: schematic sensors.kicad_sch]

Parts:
C13, C14, C15, C16, C17: 100nF; C_0402_1005Metric
MOD1: VL53L1X; JST_XH_B6B-XH-A_1x06_P2.50mm_Vertical
R12, R15, R16: 10k; R_0603_1608Metric
R13, R14: 4.7k; R_0603_1608Metric
TP9: TP9; TestPoint_Pad_D1.5mm
TP10: TP10; TestPoint_Pad_D1.5mm
U5: BMI270; Bosch_LGA-14_3x2.5mm_P0.5mm
U6: BH1750FVI; BH1750FVI_WSOF6

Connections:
DVI: C16.1, R12.2, U6.5 (DVI)
I2C_SCL: MOD1.4, R14.1, TP10.1, U5.13 (SCx), U6.6 (SCL); also elsewhere on the board
I2C_SDA: MOD1.3, R13.1, TP9.1, U5.14 (SDx), U6.4 (SDA); also elsewhere on the board
IMU_INT: U5.4 (INT1); also elsewhere on the board
LIDAR_INT: MOD1.6, R16.1; also elsewhere on the board
LIDAR_XSHUT: MOD1.5, R15.1; also elsewhere on the board

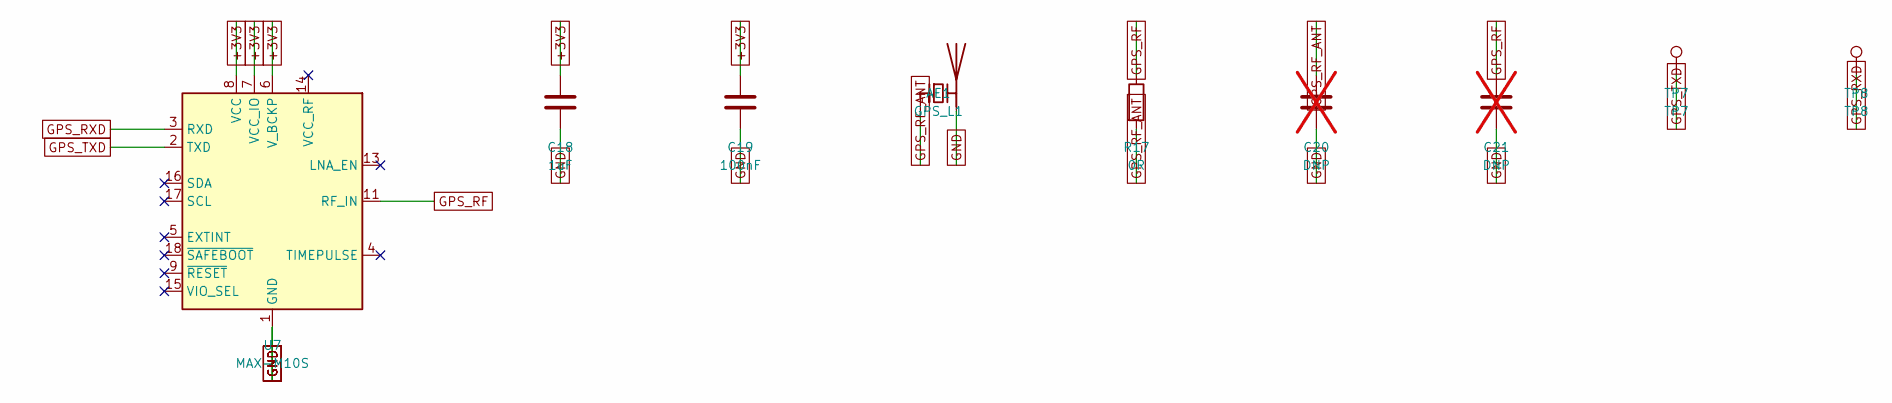
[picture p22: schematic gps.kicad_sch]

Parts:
AE1: GPS_L1; Pulse_W3011
C18: 1uF; C_0402_1005Metric
C19: 100nF; C_0402_1005Metric
C20, C21: DNP; C_0402_1005Metric; not fitted
R17: 0R; R_0402_1005Metric
TP7: TP7; TestPoint_Pad_D1.5mm
TP8: TP8; TestPoint_Pad_D1.5mm
U7: MAX-M10S; ublox_MAX

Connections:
GPS_RF: C21.1, R17.1, U7.11 (RF_IN)
GPS_RF_ANT: AE1.1 (FEED), C20.1, R17.2
GPS_RXD: TP8.1, U7.3 (RXD); also elsewhere on the board
GPS_TXD: TP7.1, U7.2 (TXD); also elsewhere on the board

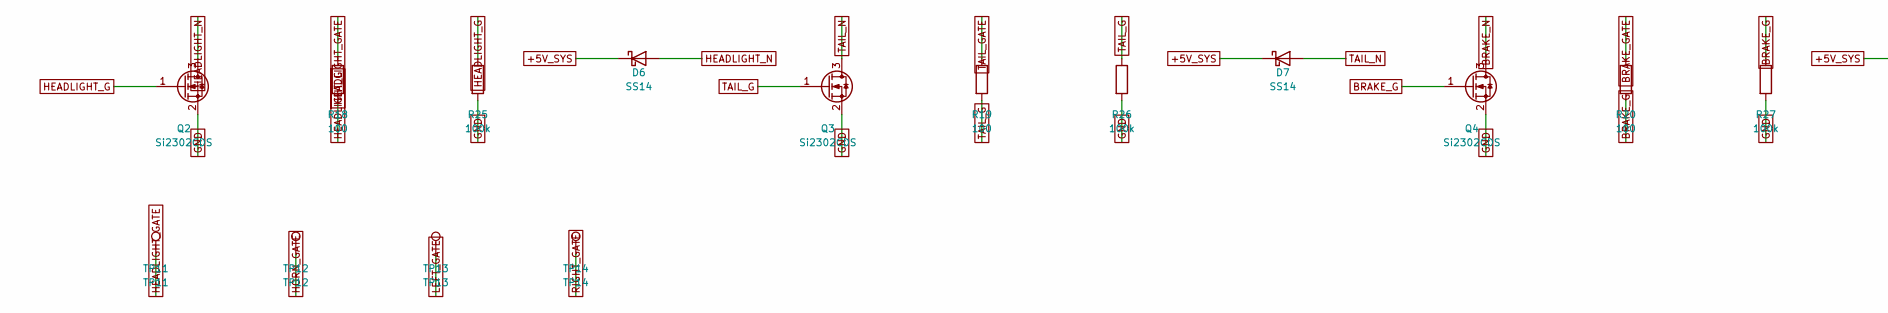
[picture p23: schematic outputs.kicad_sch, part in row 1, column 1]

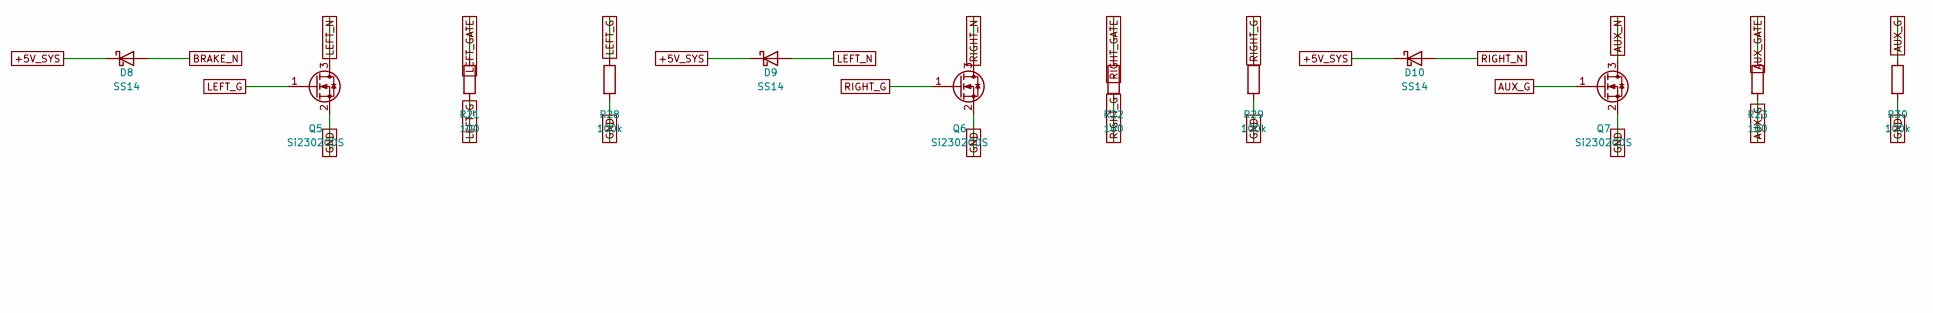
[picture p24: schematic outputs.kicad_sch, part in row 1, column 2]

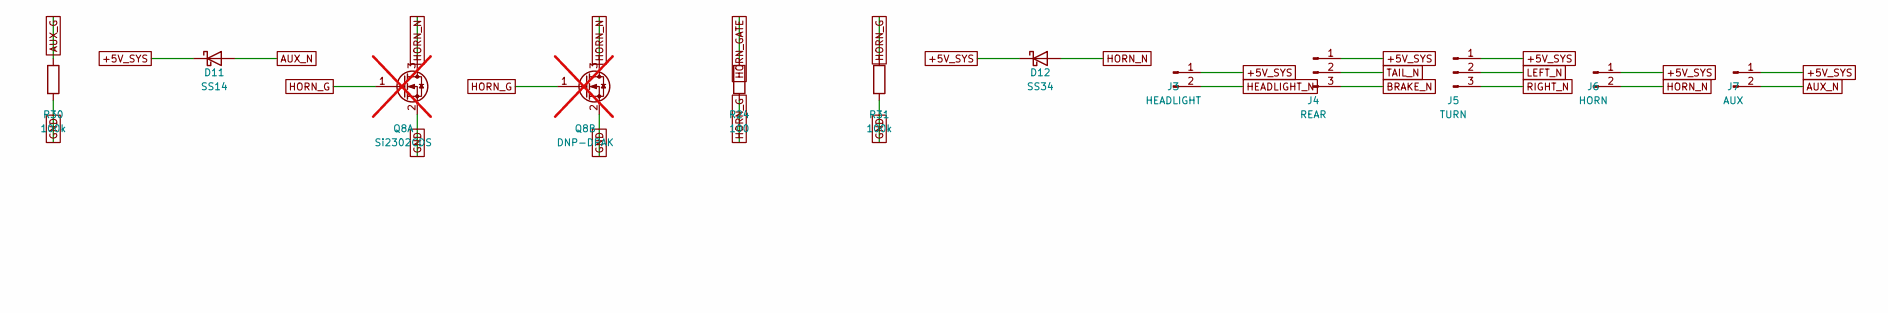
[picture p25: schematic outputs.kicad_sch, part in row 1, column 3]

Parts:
D6, D7, D8, D9, D10, D11: SS14; D_SMA
D12: SS34; D_SMA
J3: HEADLIGHT; JST_XH_B2B-XH-AM_1x02_P2.50mm_Vertical
J4: REAR; JST_XH_B3B-XH-A_1x03_P2.50mm_Vertical
J5: TURN; JST_XH_B3B-XH-A_1x03_P2.50mm_Vertical
J6: HORN; JST_XH_B2B-XH-AM_1x02_P2.50mm_Vertical
J7: AUX; JST_XH_B2B-XH-AM_1x02_P2.50mm_Vertical
Q2, Q3, Q4, Q5, Q6, Q7: Si2302CDS; SOT-23
Q8A: Si2302CDS; SOT-23; not fitted
Q8B: DNP-DPAK; TO-252-2_GSD; not fitted
R18, R19, R20, R21, R22, R23, R24: 100; R_0603_1608Metric
R25, R26, R27, R28, R29, R30, R31: 100k; R_0603_1608Metric
TP11: TP11; TestPoint_Pad_D1.5mm
TP12: TP12; TestPoint_Pad_D1.5mm
TP13: TP13; TestPoint_Pad_D1.5mm
TP14: TP14; TestPoint_Pad_D1.5mm

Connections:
AUX_G: Q7.1 (G), R23.2, R30.1
AUX_GATE: R23.1; also elsewhere on the board
AUX_N: D11.2 (A), J7.2, Q7.3 (D)
BRAKE_G: Q4.1 (G), R20.2, R27.1
BRAKE_GATE: R20.1; also elsewhere on the board
BRAKE_N: D8.2 (A), J4.3, Q4.3 (D)
HEADLIGHT_G: Q2.1 (G), R18.2, R25.1
HEADLIGHT_GATE: R18.1, TP11.1; also elsewhere on the board
HEADLIGHT_N: D6.2 (A), J3.2, Q2.3 (D)
HORN_G: Q8A.1 (G), Q8B.1 (G), R24.2, R31.1
HORN_GATE: R24.1, TP12.1; also elsewhere on the board
HORN_N: D12.2 (A), J6.2, Q8A.3 (D), Q8B.3 (D)
LEFT_G: Q5.1 (G), R21.2, R28.1
LEFT_GATE: R21.1, TP13.1; also elsewhere on the board
LEFT_N: D9.2 (A), J5.2, Q5.3 (D)
RIGHT_G: Q6.1 (G), R22.2, R29.1
RIGHT_GATE: R22.1, TP14.1; also elsewhere on the board
RIGHT_N: D10.2 (A), J5.3, Q6.3 (D)
TAIL_G: Q3.1 (G), R19.2, R26.1
TAIL_GATE: R19.1; also elsewhere on the board
TAIL_N: D7.2 (A), J4.2, Q3.3 (D)

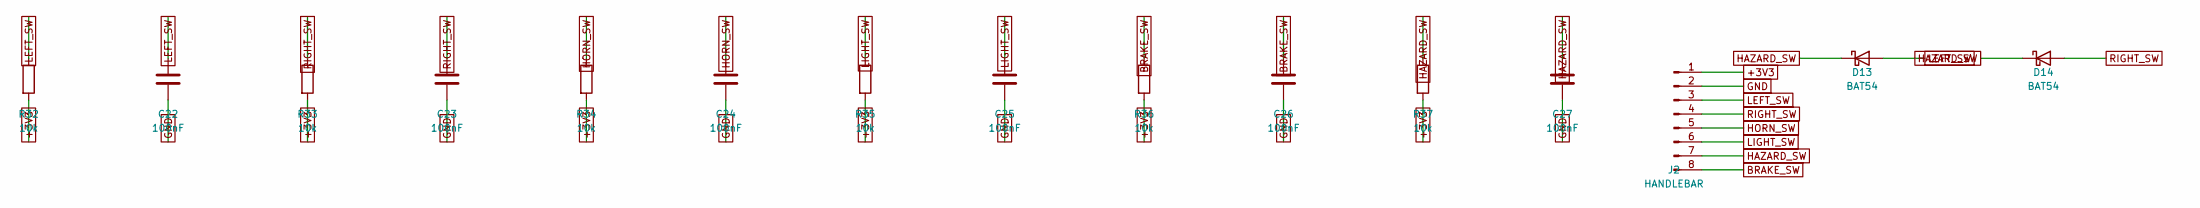
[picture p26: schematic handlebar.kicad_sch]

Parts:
C22, C23, C24, C25, C26, C27: 100nF; C_0402_1005Metric
D13, D14: BAT54; D_SOD-123
J2: HANDLEBAR; JST_XH_B8B-XH-A_1x08_P2.50mm_Vertical
R32, R33, R34, R35, R36, R37: 10k; R_0603_1608Metric

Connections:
BRAKE_SW: C26.1, J2.8, R36.1; also elsewhere on the board
HAZARD_SW: C27.1, D13.1 (K), D14.1 (K), J2.7, R37.1
HORN_SW: C24.1, J2.5, R34.1; also elsewhere on the board
LEFT_SW: C22.1, D13.2 (A), J2.3, R32.1; also elsewhere on the board
LIGHT_SW: C25.1, J2.6, R35.1; also elsewhere on the board
RIGHT_SW: C23.1, D14.2 (A), J2.4, R33.1; also elsewhere on the board

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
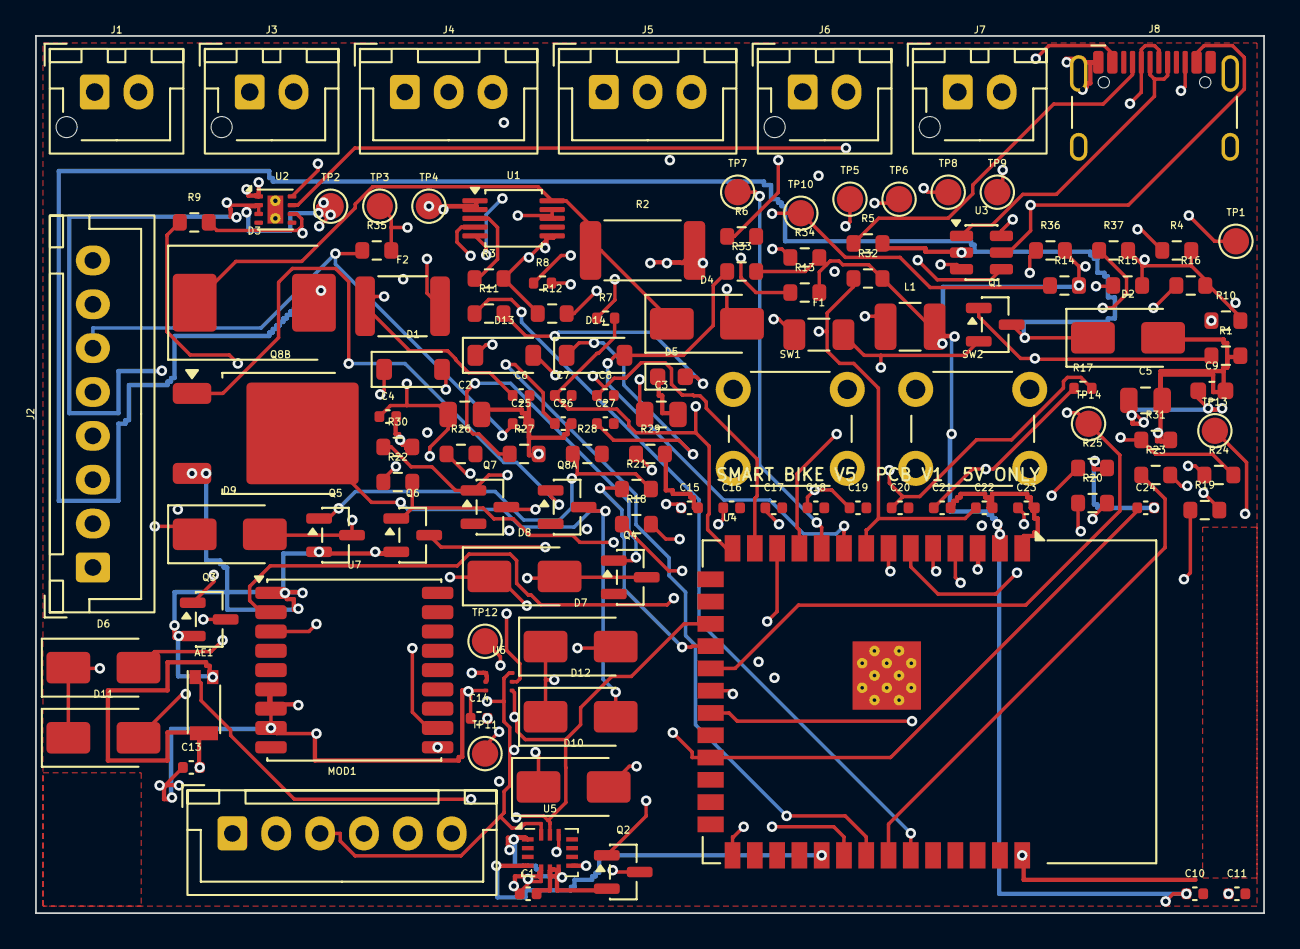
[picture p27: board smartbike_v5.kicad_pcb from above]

Board: 4 copper layers, 70.0 x 50.0 mm, 122 parts (0 on the bottom side), 62 nets.

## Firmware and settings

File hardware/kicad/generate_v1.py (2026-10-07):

#!/usr/bin/env python3
"""Generate the Smart Bike Controller V1 KiCad schematic and PCB."""

import math
import shutil
import uuid
from pathlib import Path

KICAD = Path("/home/oran/opt/kicad-root/usr/share/kicad")
ROOT = Path("/home/oran/latuan/v5/hardware/kicad/smartbike_v5")
SYM = KICAD / "symbols"
FP = KICAD / "footprints"

NS = uuid.UUID("6f0b9a1e-4c2d-4a7e-9b11-0a5d8e3c7f21")


def uid(name):
    return str(uuid.uuid5(NS, name))


def fmt(v):
    s = f"{float(v):.4f}"
    if "." in s:
        s = s.rstrip("0").rstrip(".")
    return s if s not in ("", "-0") else "0"


class Part:
    def __init__(self, ref, lib_id, value, footprint, pinmap, sheet, group, dnp=False):
        self.ref = ref
        self.lib_id = lib_id
        self.value = value
        self.footprint = footprint
        self.pinmap = pinmap
        self.sheet = sheet
        self.group = group
        self.dnp = dnp
        self.pins = {}
        self.sx = 0.0
        self.sy = 0.0


def parse_sexp(text):
    s = text
    i = 0
    n = len(s)

    def rec():
        nonlocal i
        while i < n and s[i].isspace():
            i += 1
        if i >= n:
            raise ValueError("unexpected eof")
        if s[i] == "(":
            i += 1
            items = []
            while True:
                while i < n and s[i].isspace():
                    i += 1
                if i < n and s[i] == ")":
                    i += 1
                    return items
                items.append(rec())
        if s[i] == '"':
            i += 1
            buf = []
            while i < n:
                if s[i] == "\\":
                    i += 1
                    buf.append(s[i])
                    i += 1
                    continue
                if s[i] == '"':
                    i += 1
                    break
                buf.append(s[i])
                i += 1
            return "".join(buf)
        start = i
        while i < n and (not s[i].isspace()) and s[i] not in "()":
            i += 1
        return s[start:i]

    return rec()


def extract_symbol(text, name):
    key = f'(symbol "{name}"'
    i = text.find(key)
    if i < 0:
        raise KeyError(name)
    # The closing quote is part of key, so a longer name such as NAME_1_1 does not match.
    depth = 0
    in_str = False
    j = i
    while j < len(text):
        c = text[j]
        if in_str:
            if c == "\\":
                j += 2
                continue
            if c == '"':
                in_str = False
            j += 1
            continue
        if c == '"':
            in_str = True
            j += 1
            continue
        if c == "(":
            depth += 1
        elif c == ")":
            depth -= 1
            if depth == 0:
                return text[i : j + 1]
        j += 1
    raise ValueError(f"unclosed symbol {name}")


class LibCache:
    def __init__(self):
        self.files = {}
        self.trees = {}

    def text(self, filename):
        if filename not in self.files:
            self.files[filename] = (SYM / filename).read_text(errors="replace")
        return self.files[filename]

    def symbols(self, filename):
        if filename not in self.trees:
            tree = parse_sexp(self.text(filename))
            self.trees[filename] = {
                node[1]: node
                for node in tree[1:]
                if isinstance(node, list) and node and node[0] == "symbol"
            }
        return self.trees[filename]

    def resolved_pins(self, filename, name):
        syms = self.symbols(filename)
        sym = syms[name]
        parent = sym
        for child in sym:
            if isinstance(child, list) and child and child[0] == "extends":
                parent = syms[child[1]]
                break
        pins = []

        def walk(node):
            if isinstance(node, list) and node and node[0] == "pin":
                num = pname = None
                at = (0.0, 0.0, 0.0)
                for c in node:
                    if isinstance(c, list) and c and c[0] == "name":
                        pname = c[1]
                    elif isinstance(c, list) and c and c[0] == "number":
                        num = str(c[1])
                    elif isinstance(c, list) and c and c[0] == "at":
                        at = (float(c[1]), float(c[2]), float(c[3]))
                pins.append((num, pname, node[1], at))
            elif isinstance(node, list):
                for c in node:
                    walk(c)

        walk(parent)
        return pins

    def embed_blocks(self, lib_id):
        lib, name = lib_id.split(":")
        filename = f"{lib}.kicad_sym"
        raw = extract_symbol(self.text(filename), name)
        syms = self.symbols(filename)
        extends = None
        for child in syms[name]:
            if isinstance(child, list) and child and child[0] == "extends":
                extends = child[1]
                break
        if extends:
            # KiCad 9 rejects an embedded symbol that uses extends, even when the
            # parent is embedded beside it. Paste the parent body under the
            # derived symbol's name. Pinout is inherited, so this is equivalent.
            raw = extract_symbol(self.text(filename), extends)
            raw = raw.replace(f'(symbol "{extends}"', f'(symbol "{lib_id}"', 1)
            raw = raw.replace(f'(symbol "{extends}_', f'(symbol "{name}_')
            return [raw]
        raw = raw.replace(f'(symbol "{name}"', f'(symbol "{lib_id}"', 1)
        return [raw]


LIBS = LibCache()


def resolve(part):
    lib, name = part.lib_id.split(":")
    pins = LIBS.resolved_pins(f"{lib}.kicad_sym", name)
    by_name = {}
    for num, pname, typ, at in pins:
        by_name.setdefault(pname, []).append(num)
    assigned = {num: None for num, pname, typ, at in pins}
    for key, net in part.pinmap.items():
        if key.startswith("#"):
            num = key[1:]
            if num not in assigned:
                raise SystemExit(f"{part.ref}: pin {num} not on {part.lib_id}")
            assigned[num] = net
        elif key in by_name:
            for num in by_name[key]:
                assigned[num] = net
        elif key in assigned:
            assigned[key] = net
        else:
            raise SystemExit(f"{part.ref}: pin {key} not on {part.lib_id} ({sorted(by_name)})")
    part.pins = assigned
    part.pin_geom = {num: (at, typ) for num, pname, typ, at in pins}
    return part


R0603 = "Resistor_SMD:R_0603_1608Metric"
R0402 = "Resistor_SMD:R_0402_1005Metric"
R2512 = "Resistor_SMD:R_2512_6332Metric"
C0402 = "Capacitor_SMD:C_0402_1005Metric"
C0603 = "Capacitor_SMD:C_0603_1608Metric"
C0805 = "Capacitor_SMD:C_0805_2012Metric"
DSMA = "Diode_SMD:D_SMA"
DSMC = "Diode_SMD:D_SMC"
DSOD = "Diode_SMD:D_SOD-123"
SOT23 = "Package_TO_SOT_SMD:SOT-23"
NMOS = "Transistor_FET:Q_NMOS_GSD"
PMOS = "Transistor_FET:Q_PMOS_GSD"


def R(ref, value, footprint, a, b, sheet, group, dnp=False):
    return Part(ref, "Device:R", value, footprint, {"1": a, "2": b}, sheet, group, dnp)


def C(ref, value, footprint, a, b, sheet, group, dnp=False):
    return Part(ref, "Device:C", value, footprint, {"1": a, "2": b}, sheet, group, dnp)


def diode(ref, value, footprint, cathode, anode, sheet, group, lib="Device:D_Schottky"):
    return Part(ref, lib, value, footprint, {"1": cathode, "2": anode}, sheet, group)


def nmos(ref, value, footprint, gate, drain, source, sheet, group, dnp=False):
    return Part(ref, NMOS, value, footprint, {"1": gate, "3": drain, "2": source}, sheet, group, dnp)


def build_parts():
    p = []
    # Power
    p += [
        Part("J1", "Connector:Conn_01x02_Pin", "POWER", "Connector_JST:JST_XH_B2B-XH-AM_1x02_P2.50mm_Vertical",
             {"Pin_1": "+5V_IN", "Pin_2": "GND"}, "power", "conn"),
        Part("F1", "Device:Fuse", "3A", "Fuse:Fuse_1206_3216Metric", {"1": "+5V_IN", "2": "+5V_FUSED"}, "power", "power"),
        Part("Q1", PMOS, "DMG2305UX", SOT23, {"1": "Q1_GATE", "2": "+5V_FUSED", "3": "+5V_PROT"}, "power", "power"),
        R("R1", "100k", R0603, "Q1_GATE", "GND", "power", "power"),
        diode("D1", "BZT52C5V6", DSOD, "+5V_FUSED", "Q1_GATE", "power", "power", "Device:D_Zener"),
        diode("D2", "SMAJ5.0A", DSMA, "+5V_PROT", "GND", "power", "power", "Device:D"),
        diode("D3", "SS54", DSMC, "+5V_MERGED", "+5V_PROT", "power", "power"),
        Part("F2", "Device:Fuse", "1.1A", "Fuse:Fuse_1812_4532Metric", {"1": "USB_VBUS", "2": "USB_VBUS_FUSED"}, "power", "power"),
        diode("D4", "SS34", DSMA, "+5V_MERGED", "USB_VBUS_FUSED", "power", "power"),
        R("R2", "10m", R2512, "+5V_MERGED", "+5V_SYS", "power", "power"),
        C("C2", "22uF", C0805, "+5V_SYS", "GND", "power", "power"),
        Part("U1", "smartbike:INA228", "INA228", "Package_SO:VSSOP-10_3x3mm_P0.5mm", {
            "Vbus": "+5V_SYS", "Vin+": "+5V_MERGED", "Vin-": "+5V_SYS", "VS": "+3V3", "GND": "GND",
            "A1": "GND", "A0": "GND", "SDA": "I2C_SDA", "SCL": "I2C_SCL", "~{Alert}": "ALERT",
        }, "power", "power"),
        C("C1", "100nF", C0402, "+3V3", "GND", "power", "power"),
        R("R3", "10k", R0603, "ALERT", "+3V3", "power", "power"),
        Part("U2", "smartbike:TPS62162DSG", "TPS62162-Q1",
             "Package_SON:WSON-8-1EP_2x2mm_P0.5mm_EP0.9x1.6mm_ThermalVias", {
                 "VIN": "+5V_SYS", "EN": "+5V_SYS", "PG": "PGOOD", "PAD": "GND", "PGND": "GND",
                 "AGND": "GND", "SW": "SW", "VOS": "+3V3", "FB": "GND",
             }, "power", "power"),
        Part("L1", "Device:L", "2.2uH", "Inductor_SMD:L_1210_3225Metric", {"1": "SW", "2": "+3V3"}, "power", "power"),
        C("C3", "10uF", C0805, "+5V_SYS", "GND", "power", "power"),
        C("C4", "100nF", C0402, "+5V_SYS", "GND", "power", "power"),
        C("C5", "22uF", C0805, "+3V3", "GND", "power", "power"),
        R("R4", "100k", R0603, "PGOOD", "+3V3", "power", "power"),
    ]
    # USB
    p += [
        Part("J8", "Connector:USB_C_Receptacle_USB2.0_16P", "USB-C",
             "Connector_USB:USB_C_Receptacle_HCTL_HC-TYPE-C-16P-01A", {
                 "VBUS": "USB_VBUS", "GND": "GND", "SHIELD": "GND", "CC1": "CC1", "CC2": "CC2",
                 "D+": "USB_D_P_CONN", "D-": "USB_D_N_CONN",
             }, "usb", "usb"),
        R("R5", "5.1k", R0603, "CC1", "GND", "usb", "usb"),
        R("R6", "5.1k", R0603, "CC2", "GND", "usb", "usb"),
        Part("U3", "smartbike:USBLC6-2SC6", "USBLC6-2SC6", "Package_TO_SOT_SMD:SOT-23-6", {
            "#1": "USB_D_P_CONN", "#6": "USB_D_P_ESD", "#3": "USB_D_N_CONN", "#4": "USB_D_N_ESD",
            "#5": "USB_VBUS", "#2": "GND",
        }, "usb", "usb"),
        C("C6", "100nF", C0402, "USB_VBUS", "GND", "usb", "usb"),
        R("R7", "22", R0402, "USB_D_P_ESD", "USB_D_P", "usb", "usb"),
        R("R8", "22", R0402, "USB_D_N_ESD", "USB_D_N", "usb", "usb"),
        C("C7", "DNP", C0402, "USB_D_P", "GND", "usb", "usb", dnp=True),
        C("C8", "DNP", C0402, "USB_D_N", "GND", "usb", "usb", dnp=True),
    ]
    # MCU
    esp = {f"IO{n}": None for n in []}
    esp_map = {
        "3V3": "+3V3", "GND": "GND", "EN": "EN", "IO0": "BOOT",
        "IO4": "LIDAR_XSHUT", "IO5": "LIDAR_INT", "IO6": "HORN_GATE", "IO7": "HEADLIGHT_GATE",
        "IO8": "I2C_SDA", "IO9": "I2C_SCL", "IO10": "LEFT_GATE", "IO11": "RIGHT_GATE",
        "IO12": "TAIL_GATE", "IO13": "BRAKE_GATE", "IO15": "LEFT_SW", "IO16": "RIGHT_SW",
        "IO17": "GPS_TXD", "IO18": "GPS_RXD", "USB_D-": "USB_D_N", "USB_D+": "USB_D_P",
        "IO21": "HORN_SW", "IO38": "IMU_INT", "IO39": "LIGHT_SW", "IO40": "BRAKE_SW",
        "IO41": "AUX_GATE", "IO42": "STATUS_LED",
    }
    p += [
        Part("U4", "RF_Module:ESP32-S3-WROOM-1", "ESP32-S3-WROOM-1-N8", "smartbike:ESP32-S3-WROOM-1", esp_map, "mcu", "mcu"),
        C("C9", "10uF", C0603, "+3V3", "GND", "mcu", "mcu"),
        C("C10", "100nF", C0402, "+3V3", "GND", "mcu", "mcu"),
        R("R9", "10k", R0603, "EN", "+3V3", "mcu", "mcu"),
        C("C11", "1uF", C0402, "EN", "GND", "mcu", "mcu"),
        Part("SW1", "Switch:SW_Push", "RESET", "Button_Switch_THT:SW_PUSH_6mm", {"1": "EN", "2": "GND"}, "mcu", "mcu"),
        R("R10", "10k", R0603, "BOOT", "+3V3", "mcu", "mcu"),
        Part("SW2", "Switch:SW_Push", "BOOT", "Button_Switch_THT:SW_PUSH_6mm", {"1": "BOOT", "2": "GND"}, "mcu", "mcu"),
        R("R11", "330", R0603, "STATUS_LED", "STATUS_LED_A", "mcu", "mcu"),
        diode("D5", "GREEN", "LED_SMD:LED_0603_1608Metric", "GND", "STATUS_LED_A", "mcu", "mcu", "Device:LED"),
    ]
    # Sensors
    p += [
        R("R13", "4.7k", R0603, "I2C_SDA", "+3V3", "sensors", "sensors"),
        R("R14", "4.7k", R0603, "I2C_SCL", "+3V3", "sensors", "sensors"),
        Part("U5", "smartbike:BMI270", "BMI270", "Package_LGA:Bosch_LGA-14_3x2.5mm_P0.5mm", {
            "SDO": "GND", "SDx": "I2C_SDA", "SCx": "I2C_SCL", "CSB": "+3V3", "INT1": "IMU_INT",
            "VDDIO": "+3V3", "GNDIO": "GND", "VDD": "+3V3", "GND": "GND",
        }, "sensors", "sensors"),
        C("C13", "100nF", C0402, "+3V3", "GND", "sensors", "sensors"),
        C("C14", "100nF", C0402, "+3V3", "GND", "sensors", "sensors"),
        Part("U6", "smartbike:BH1750FVI", "BH1750FVI", "smartbike:BH1750FVI_WSOF6", {
            "VCC": "+3V3", "ADDR": "GND", "GND": "GND", "SDA": "I2C_SDA", "DVI": "DVI", "SCL": "I2C_SCL",
        }, "sensors", "sensors"),
        C("C15", "100nF", C0402, "+3V3", "GND", "sensors", "sensors"),
        R("R12", "10k", R0603, "+3V3", "DVI", "sensors", "sensors"),
        C("C16", "100nF", C0402, "DVI", "GND", "sensors", "sensors"),
        Part("MOD1", "Connector:Conn_01x06_Pin", "VL53L1X", "Connector_JST:JST_XH_B6B-XH-A_1x06_P2.50mm_Vertical", {
            "Pin_1": "+3V3", "Pin_2": "GND", "Pin_3": "I2C_SDA", "Pin_4": "I2C_SCL",
            "Pin_5": "LIDAR_XSHUT", "Pin_6": "LIDAR_INT",
        }, "sensors", "lidar"),
        R("R15", "10k", R0603, "LIDAR_XSHUT", "+3V3", "sensors", "sensors"),
        R("R16", "10k", R0603, "LIDAR_INT", "+3V3", "sensors", "sensors"),
        C("C17", "100nF", C0402, "+3V3", "GND", "sensors", "sensors"),
    ]
    # GPS
    p += [
        Part("U7", "RF_GPS:MAX-M10S", "MAX-M10S", "RF_GPS:ublox_MAX", {
            "TXD": "GPS_TXD", "RXD": "GPS_RXD", "VCC": "+3V3", "VCC_IO": "+3V3", "V_BCKP": "+3V3",
            "GND": "GND", "RF_IN": "GPS_RF",
        }, "gps", "gps"),
        C("C18", "1uF", C0402, "+3V3", "GND", "gps", "gps"),
        C("C19", "100nF", C0402, "+3V3", "GND", "gps", "gps"),
        Part("AE1", "Device:Antenna_Chip", "GPS_L1", "RF_Antenna:Pulse_W3011", {"FEED": "GPS_RF", "PCB_Trace": "GND"}, "gps", "antenna"),
        R("R17", "0R", R0402, "GPS_RF", "GPS_RF_ANT", "gps", "gps"),
        C("C20", "DNP", C0402, "GPS_RF_ANT", "GND", "gps", "gps", dnp=True),
        C("C21", "DNP", C0402, "GPS_RF", "GND", "gps", "gps", dnp=True),
    ]
    # The antenna feed is pin FEED. R17 sits in series, so FEED net must be the module side
    # only if we insert the resistor. Reconnect AE1 feed to the antenna side.
    for part in p:
        if part.ref == "AE1":
            part.pinmap["FEED"] = "GPS_RF_ANT"
    # Outputs
    channels = [
        ("Q2", "Si2302CDS", "HEADLIGHT_GATE", "HEADLIGHT_N", "R18", "R25", "D6", "SS14", DSMA),
        ("Q3", "Si2302CDS", "TAIL_GATE", "TAIL_N", "R19", "R26", "D7", "SS14", DSMA),
        ("Q4", "Si2302CDS", "BRAKE_GATE", "BRAKE_N", "R20", "R27", "D8", "SS14", DSMA),
        ("Q5", "Si2302CDS", "LEFT_GATE", "LEFT_N", "R21", "R28", "D9", "SS14", DSMA),
        ("Q6", "Si2302CDS", "RIGHT_GATE", "RIGHT_N", "R22", "R29", "D10", "SS14", DSMA),
        ("Q7", "Si2302CDS", "AUX_GATE", "AUX_N", "R23", "R30", "D11", "SS14", DSMA),
    ]
    for ref, val, gate, drain, rs, rg, dref, dval, dfp in channels:
        p.append(nmos(ref, val, SOT23, gate, drain, "GND", "outputs", "fet"))
        p.append(R(rs, "100", R0603, gate, gate + "_G", "outputs", "fet"))
        p.append(R(rg, "100k", R0603, gate + "_G", "GND", "outputs", "fet"))
        p.append(diode(dref, dval, dfp, "+5V_SYS", drain, "outputs", "fet"))
    # Gate nets in the table above are the GPIO nets. Series resistor must sit between GPIO and gate.
    # Fix: GPIO -- series -- gate node, pulldown on gate node. I used gate as both ends.
    # Rebuild those six channels cleanly below by replacing the mistaken nets.
    p = [part for part in p if part.sheet != "outputs"]
    channels = [
        ("Q2", "HEADLIGHT_GATE", "HEADLIGHT_G", "HEADLIGHT_N", "R18", "R25", "D6"),
        ("Q3", "TAIL_GATE", "TAIL_G", "TAIL_N", "R19", "R26", "D7"),
        ("Q4", "BRAKE_GATE", "BRAKE_G", "BRAKE_N", "R20", "R27", "D8"),
        ("Q5", "LEFT_GATE", "LEFT_G", "LEFT_N", "R21", "R28", "D9"),
        ("Q6", "RIGHT_GATE", "RIGHT_G", "RIGHT_N", "R22", "R29", "D10"),
        ("Q7", "AUX_GATE", "AUX_G", "AUX_N", "R23", "R30", "D11"),
    ]
    for q, gpio, gate, drain, rs, rg, dref in channels:
        p.append(nmos(q, "Si2302CDS", SOT23, gate, drain, "GND", "outputs", "fet"))
        p.append(R(rs, "100", R0603, gpio, gate, "outputs", "fet"))
        p.append(R(rg, "100k", R0603, gate, "GND", "outputs", "fet"))
        p.append(diode(dref, "SS14", DSMA, "+5V_SYS", drain, "outputs", "fet"))
    p += [
        nmos("Q8A", "Si2302CDS", SOT23, "HORN_G", "HORN_N", "GND", "outputs", "fet", dnp=True),
        nmos("Q8B", "DNP-DPAK", "smartbike:TO-252-2_GSD", "HORN_G", "HORN_N", "GND", "outputs", "fet", dnp=True),
        R("R24", "100", R0603, "HORN_GATE", "HORN_G", "outputs", "fet"),
        R("R31", "100k", R0603, "HORN_G", "GND", "outputs", "fet"),
        diode("D12", "SS34", DSMA, "+5V_SYS", "HORN_N", "outputs", "fet"),
        Part("J3", "Connector:Conn_01x02_Pin", "HEADLIGHT", "Connector_JST:JST_XH_B2B-XH-AM_1x02_P2.50mm_Vertical",
             {"Pin_1": "+5V_SYS", "Pin_2": "HEADLIGHT_N"}, "outputs", "conn"),
        Part("J4", "Connector:Conn_01x03_Pin", "REAR", "Connector_JST:JST_XH_B3B-XH-A_1x03_P2.50mm_Vertical",
             {"Pin_1": "+5V_SYS", "Pin_2": "TAIL_N", "Pin_3": "BRAKE_N"}, "outputs", "conn"),
        Part("J5", "Connector:Conn_01x03_Pin", "TURN", "Connector_JST:JST_XH_B3B-XH-A_1x03_P2.50mm_Vertical",
             {"Pin_1": "+5V_SYS", "Pin_2": "LEFT_N", "Pin_3": "RIGHT_N"}, "outputs", "conn"),
        Part("J6", "Connector:Conn_01x02_Pin", "HORN", "Connector_JST:JST_XH_B2B-XH-AM_1x02_P2.50mm_Vertical",
             {"Pin_1": "+5V_SYS", "Pin_2": "HORN_N"}, "outputs", "conn"),
        Part("J7", "Connector:Conn_01x02_Pin", "AUX", "Connector_JST:JST_XH_B2B-XH-AM_1x02_P2.50mm_Vertical",
             {"Pin_1": "+5V_SYS", "Pin_2": "AUX_N"}, "outputs", "conn"),
    ]
    # Handlebar
    switches = [
        ("LEFT_SW", "R32", "C22"),
        ("RIGHT_SW", "R33", "C23"),
        ("HORN_SW", "R34", "C24"),
        ("LIGHT_SW", "R35", "C25"),
        ("BRAKE_SW", "R36", "C26"),
        ("HAZARD_SW", "R37", "C27"),
    ]
    for net, rr, cc in switches:
        p.append(R(rr, "10k", R0603, net, "+3V3", "handlebar", "logic"))
        p.append(C(cc, "100nF", C0402, net, "GND", "handlebar", "logic"))
    p += [
        Part("J2", "Connector:Conn_01x08_Pin", "HANDLEBAR", "Connector_JST:JST_XH_B8B-XH-A_1x08_P2.50mm_Vertical", {
            "Pin_1": "+3V3", "Pin_2": "GND", "Pin_3": "LEFT_SW", "Pin_4": "RIGHT_SW",
            "Pin_5": "HORN_SW", "Pin_6": "LIGHT_SW", "Pin_7": "HAZARD_SW", "Pin_8": "BRAKE_SW",
        }, "handlebar", "conn"),
        diode("D13", "BAT54", DSOD, "HAZARD_SW", "LEFT_SW", "handlebar", "logic"),
        diode("D14", "BAT54", DSOD, "HAZARD_SW", "RIGHT_SW", "handlebar", "logic"),
    ]
    # Test points
    tps = [
        ("TP1", "+5V_IN"), ("TP2", "+5V_SYS"), ("TP3", "+3V3"), ("TP4", "GND"),
        ("TP5", "USB_D_P"), ("TP6", "USB_D_N"), ("TP7", "GPS_TXD"), ("TP8", "GPS_RXD"),
        ("TP9", "I2C_SDA"), ("TP10", "I2C_SCL"), ("TP11", "HEADLIGHT_GATE"),
        ("TP12", "HORN_GATE"), ("TP13", "LEFT_GATE"), ("TP14", "RIGHT_GATE"),
    ]
    for ref, net in tps:
        sheet = "power" if net in ("+5V_IN", "+5V_SYS", "+3V3", "GND") else "mcu"
        if net.startswith("GPS"):
            sheet = "gps"
        if net.startswith("I2C"):
            sheet = "sensors"
        if net.endswith("GATE"):
            sheet = "outputs"
        if net.startswith("USB"):
            sheet = "usb"
        p.append(Part(ref, "Connector:TestPoint", ref, "TestPoint:TestPoint_Pad_D1.5mm", {"1": net}, sheet, "tp"))
    for part in p:
        resolve(part)
    add_power_flags(p)
    return p


def add_power_flags(parts):
    types = {}
    for part in parts:
        for num, net in part.pins.items():
            if not net:
                continue
            typ = part.pin_geom[num][1]
            types.setdefault(net, set()).add(typ)
    n = 1
    for net, typset in sorted(types.items()):
        if "power_in" in typset and "power_out" not in typset:
            flag = Part(f"#PF{n}", "power:PWR_FLAG", "PWR_FLAG", "", {"1": net}, "power", "flag")
            flag.bom = False
            resolve(flag)
            parts.append(flag)
            n += 1


def effects(size=1.27, hide=False, justify=None):
    just = f"\n\t\t\t(justify {justify})" if justify else ""
    hide_s = "\n\t\t\t(hide yes)" if hide else ""
    return f"""(effects
\t\t\t(font
\t\t\t\t(size {fmt(size)} {fmt(size)})
\t\t\t){just}{hide_s}
\t\t)"""
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

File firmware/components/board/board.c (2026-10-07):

#include "board.h"

#include "driver/gpio.h"
#include "esp_attr.h"
#include "driver/ledc.h"
#include "esp_rom_gpio.h"
#include "hal/gpio_ll.h"
#include "soc/gpio_sig_map.h"

#define LEDC_MODE LEDC_LOW_SPEED_MODE
#define LEDC_TIMER LEDC_TIMER_0

enum {
    CH_HEAD = LEDC_CHANNEL_0,
    CH_TAIL = LEDC_CHANNEL_1,
    CH_LEFT = LEDC_CHANNEL_2,
    CH_RIGHT = LEDC_CHANNEL_3
};

static const gpio_num_t GATES[] = {
    BOARD_HORN_GATE, BOARD_HEAD_GATE, BOARD_LEFT_GATE, BOARD_RIGHT_GATE,
    BOARD_TAIL_GATE, BOARD_BRAKE_GATE, BOARD_AUX_GATE
};

static const gpio_num_t SWITCHES[] = {
    BOARD_LEFT_SW, BOARD_RIGHT_SW, BOARD_HORN_SW, BOARD_LIGHT_SW, BOARD_BRAKE_SW
};

static void pin_low_output(gpio_num_t pin)
{
    gpio_set_level(pin, 0);
    gpio_set_direction(pin, GPIO_MODE_OUTPUT);
    gpio_set_level(pin, 0);
}

static void ledc_bind(ledc_channel_t channel, int gpio, uint32_t duty)
{
    ledc_set_duty(LEDC_MODE, channel, duty);
    ledc_update_duty(LEDC_MODE, channel);
    ledc_set_pin(gpio, LEDC_MODE, channel);
}

void board_outputs_safe(void)
{
    for (size_t i = 0; i < sizeof GATES / sizeof GATES[0]; i++) {
        pin_low_output(GATES[i]);
    }
    pin_low_output(BOARD_STATUS_LED);
    pin_low_output(BOARD_LIDAR_XSHUT);

    ledc_timer_config_t timer = {
        .speed_mode = LEDC_MODE,
        .duty_resolution = LEDC_TIMER_10_BIT,
        .timer_num = LEDC_TIMER,
        .freq_hz = 1000,
        .clk_cfg = LEDC_AUTO_CLK,
    };
    ledc_timer_config(&timer);

    const ledc_channel_t channels[] = {CH_HEAD, CH_TAIL, CH_LEFT, CH_RIGHT};
    const int pins[] = {BOARD_HEAD_GATE, BOARD_TAIL_GATE, BOARD_LEFT_GATE, BOARD_RIGHT_GATE};
    for (int i = 0; i < 4; i++) {
        ledc_channel_config_t channel = {
            .gpio_num = pins[i],
            .speed_mode = LEDC_MODE,
            .channel = channels[i],
            .intr_type = LEDC_INTR_DISABLE,
            .timer_sel = LEDC_TIMER,
            .duty = 0,
            .hpoint = 0,
        };
        ledc_channel_config(&channel);
    }

    for (size_t i = 0; i < sizeof SWITCHES / sizeof SWITCHES[0]; i++) {
        gpio_config_t cfg = {
            .pin_bit_mask = 1ULL << SWITCHES[i],
            .mode = GPIO_MODE_INPUT,
            .pull_up_en = GPIO_PULLUP_ENABLE,
            .pull_down_en = GPIO_PULLDOWN_DISABLE,
            .intr_type = GPIO_INTR_DISABLE,
        };
        gpio_config(&cfg);
    }
    gpio_config_t imu = {
        .pin_bit_mask = 1ULL << BOARD_IMU_INT,
        .mode = GPIO_MODE_INPUT,
        .pull_up_en = GPIO_PULLUP_DISABLE,
        .pull_down_en = GPIO_PULLDOWN_DISABLE,
        .intr_type = GPIO_INTR_DISABLE,
    };
    gpio_config(&imu);
}

void board_apply(uint16_t head, uint16_t tail, uint16_t left, uint16_t right,
                 bool brake, bool horn, bool aux)
{
    ledc_bind(CH_HEAD, BOARD_HEAD_GATE, head);
    ledc_bind(CH_TAIL, BOARD_TAIL_GATE, tail);
    ledc_bind(CH_LEFT, BOARD_LEFT_GATE, left);
    ledc_bind(CH_RIGHT, BOARD_RIGHT_GATE, right);
    gpio_set_level(BOARD_BRAKE_GATE, brake ? 1 : 0);
    gpio_set_level(BOARD_HORN_GATE, horn ? 1 : 0);
    gpio_set_level(BOARD_AUX_GATE, aux ? 1 : 0);
}

void IRAM_ATTR board_failsafe_isr(void)
{
    for (size_t i = 0; i < sizeof GATES / sizeof GATES[0]; i++) {
        int pin = GATES[i];
        esp_rom_gpio_connect_out_signal(pin, SIG_GPIO_OUT_IDX, false, false);
        gpio_ll_set_level(&GPIO, pin, 0);
    }
}

void board_status_led(bool on)
{
    gpio_set_level(BOARD_STATUS_LED, on ? 1 : 0);
}

void board_xshut(bool high)
{
    gpio_set_level(BOARD_LIDAR_XSHUT, high ? 1 : 0);
}

bool board_switch_closed(int index)
{
    if (index < 0 || index >= (int)(sizeof SWITCHES / sizeof SWITCHES[0])) {
        return false;
    }
    return gpio_get_level(SWITCHES[index]) == 0;
}

bool board_imu_level(void)
{
    return gpio_get_level(BOARD_IMU_INT) != 0;
}

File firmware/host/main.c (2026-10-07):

#include "bike_ctrl.h"

#include <stdio.h>
#include <string.h>

void host_exec(const char *text, bike_reply_t *out);

static void strip(char *line)
{
    size_t n = strlen(line);
    while (n > 0 && (line[n - 1] == '\n' || line[n - 1] == '\r' || line[n - 1] == ' ')) {
        line[--n] = '\0';
    }
    char *start = line;
    while (*start == ' ') {
        start++;
    }
    if (start != line) {
        memmove(line, start, strlen(start) + 1);
    }
}

static int self_test(void)
{
    if (bike_elapsed(10u, 0xfffffff0u) != 26u) {
        fprintf(stderr, "elapsed wrap failed\n");
        return 1;
    }
    uint8_t flag = 1;
    if (bike_crc8(&flag, 1) == 0) {
        fprintf(stderr, "crc8 failed\n");
        return 1;
    }
    return 0;
}

int main(int argc, char **argv)
{
    if (argc > 1 && strcmp(argv[1], "--self-test") == 0) {
        return self_test();
    }
    bike_plant_t plant;
    bike_plant_init(&plant);
    bike_setup(&plant, false);
    setvbuf(stdout, NULL, _IOLBF, 0);
    char line[192];
    while (fgets(line, sizeof line, stdin) != NULL) {
        strip(line);
        bike_reply_t reply;
        reply.count = 0;
        if (line[0] != '\0' && line[0] != '#') {
            host_exec(line, &reply);
        }
        for (int i = 0; i < reply.count; i++) {
            printf("%s\n", reply.text[i]);
        }
        printf(".\n");
    }
    return 0;
}

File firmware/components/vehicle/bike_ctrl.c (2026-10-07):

#include "bike_ctrl.h"
#include "defaults.h"

#include <stdatomic.h>
#include <stdio.h>
#include <stdlib.h>
#include <string.h>
#include <math.h>

#define CFG_LIST(X) BIKE_CFG_LIST(X)

#define X_ENUM(name, value) CFG_##name,
enum { CFG_LIST(X_ENUM) CFG_COUNT };
#undef X_ENUM

#define X_NAME(name, value) #name,
static const char *const CFG_NAME[CFG_COUNT] = { CFG_LIST(X_NAME) };
#undef X_NAME

#define X_VAL(name, value) value,
static const int CFG_DEFAULT[CFG_COUNT] = { CFG_LIST(X_VAL) };
#undef X_VAL

enum {
    Q_NONE = 0,
    Q_RIDE_START = 1,
    Q_RIDE_STOP = 2,
    Q_ARM = 3,
    Q_DISARM = 4,
    Q_DISMISS = 5,
    Q_AUX_ON = 6,
    Q_AUX_OFF = 7,
    Q_SLEEP = 8
};

enum {
    MODE_PARKING = 0,
    MODE_RIDING,
    MODE_ALARM
};

enum {
    INHIBIT_NONE = 0,
    INHIBIT_DISARMED,
    INHIBIT_POWER,
    INHIBIT_UVLO,
    INHIBIT_OC,
    INHIBIT_FAULT
};

enum { HOLD_ON = 0, HOLD_OFF, HOLD_DUTY };

enum { CH_HEAD = 0, CH_TAIL, CH_LEFT, CH_RIGHT, CH_BRAKE, CH_HORN, CH_AUX, CH_N };

static const char *const MODE_NAME[] = {"parking", "riding", "alarm"};
static const char *const INHIBIT_NAME[] = {
    "none", "disarmed", "power", "uvlo", "oc", "fault"
};
static const uint8_t I2C_ADDR[BIKE_I2C_N] = {0x40, 0x23, 0x29, 0x68};

static const char *const HELP[] = {
    "help", "status", "inputs", "sense", "power", "gates", "faults", "config",
    "snapshot", "watch <ms>", "watch off", "arm", "disarm", "ride start",
    "ride stop", "dismiss", "aux on", "aux off", "debug on", "debug off",
    "hold <kênh> on|off|<duty>", "hold off", "inject lux <n>|off",
    "inject motion on|off", "inject clear motion", "inject range <mm>|off",
    "inject pin low|high|off", "inject off", "config set <tên> <số>",
    "config save horn_current_ma|shunt_cal", "sleep", "i2c"
};

typedef struct {
    bool used;
    int kind;
    int duty;
    uint32_t since;
} hold_t;

typedef struct {
    uint16_t head, tail, left, right;
    bool left_lit, right_lit;
    bool brake, horn, aux;
    bool horn_from_alarm;
} act_t;

typedef struct {
    bool candidate;
    bool stable;
    uint32_t candidate_since;
} sw_t;

static struct {
    bike_plant_t *plant;
    bike_hooks_t hooks;
    bike_emit_fn emit;
    void *emit_ctx;
    int cfg[CFG_COUNT];
    int nvs_horn;
    int nvs_shunt;
    uint32_t now;
    int mode;
    bool armed;
    uint8_t rtc_flag;
    uint8_t rtc_crc;
    bool fault_latch;
    bool debug;
    bool aux_latch;
    bool head_on;
    sw_t sw[5];
    uint8_t queue[4];
    uint8_t q_head;
    uint8_t q_len;
    int cmd_dropped;
    hold_t holds[CH_N];
    bool inj_lux_valid;
    uint16_t inj_lux;
    int8_t inj_motion;
    bool inj_range_valid;
    uint16_t inj_range;
    int8_t inj_pin;
    bool motion_since_valid;
    uint32_t motion_since;
    bool quiet_since_valid;
    uint32_t quiet_since;
    uint32_t alarm_since;
    uint32_t alarm_ready_at;
    bool motion_deadline_valid;
    uint32_t motion_deadline;
    bool pin_high_valid;
    uint32_t pin_high_since;
    bool motion_fault;
    bool horn_lockout;
    bool horn_since_valid;
    uint32_t horn_since;
    bool uvlo;
    bool uvlo_low_valid;
    uint32_t uvlo_low_since;
    bool uvlo_high_valid;
    uint32_t uvlo_high_since;
    uint32_t uvlo_trips[8];
    int uvlo_trip_n;
    int uvlo_count;
    bool oc_since_valid;
    uint32_t oc_since;
    int failsafe_count;
    bool stalled;
    bool failsafe_tripped;
    uint32_t last_kick;
    int sleep_phase;
    uint32_t sleep_since;
    bool xshut_high;
    bool sensors_saw_prepare;
    bool lux_valid;
    uint16_t lux_sample;
    uint32_t lux_ms;
    bool range_sample_valid;
    uint16_t range_sample;
    uint32_t range_ms;
    uint32_t power_ms;
    uint16_t bus_mv;
    int current_ma;
    uint32_t energy_mwh;
    int32_t lat_e7;
    int32_t lon_e7;
    bool gps_fix;
    bool gps_ms_valid;
    uint32_t gps_ms;
    bool scan_pending;
    bool asleep;
    act_t want;
    act_t out;
    int inhibit;
    bool motion;
    bool obstacle;
    uint16_t eff_lux;
    uint16_t eff_range;
    uint32_t watch_ms;
} g;

volatile uint32_t bike_kick_ms;
static atomic_flag q_flag = ATOMIC_FLAG_INIT;

static void q_lock(void)
{
    while (atomic_flag_test_and_set_explicit(&q_flag, memory_order_acquire)) {
    }
}

static void q_unlock(void)
{
    atomic_flag_clear_explicit(&q_flag, memory_order_release);
}

static int reply_room(const bike_reply_t *out)
{
    return out->count < BIKE_REPLY_LINES;
}

static int cfg(int id)
{
    return g.cfg[id];
}

static void say(bike_reply_t *out, const char *line, bool as_event)
{
    if (out != NULL && reply_room(out)) {
        snprintf(out->text[out->count], BIKE_REPLY_LEN, "%s", line);
        out->count++;
    }
    if (as_event && g.emit != NULL) {
        g.emit(line, g.emit_ctx);
    }
}

uint8_t bike_crc8(const uint8_t *data, size_t len)
{
    uint8_t crc = 0;
    for (size_t i = 0; i < len; i++) {
        crc ^= data[i];
        for (int bit = 0; bit < 8; bit++) {
            if ((crc & 0x80u) != 0) {
                crc = (uint8_t)((crc << 1) ^ 0x07u);
            } else {
                crc = (uint8_t)(crc << 1);
            }
        }
    }
    return crc;
}

static void store_rtc(void)
{
    uint8_t flag = g.armed ? 1u : 0u;
    g.rtc_flag = flag;
    g.rtc_crc = bike_crc8(&flag, 1);
}

static bool rtc_ok(void)
{
    return g.rtc_crc == bike_crc8(&g.rtc_flag, 1);
}
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

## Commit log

2026-10-07 Add Smart Bike Controller V1 firmware, design, and hardware.
    The control core matches the host simulator, and the ESP-IDF project builds for ESP32-S3.
    [gps.kicad_sch, handlebar.kicad_sch, mcu.kicad_sch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]
2026-10-07 Add the ESP-IDF v5.5.5 source tree.
    A fresh clone should contain the same sources used to build the firmware.
    [.uncrustify.cfg, anti_rollback_partition.csv, cmn_crt_authorities.csv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]
